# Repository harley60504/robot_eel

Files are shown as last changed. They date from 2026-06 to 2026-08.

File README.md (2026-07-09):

# Robot Eel

This repository contains the robot eel desktop release, ESP32 firmware, MuJoCo simulation and PPO/RL training tools, mobile Flutter app sources, real-video analysis scripts, and 3D-print assets.

## Folder Layout

- `Release/` - Packaged Windows desktop app plus the desktop Python backend.
- `robot_eel/` - ESP32 camera-board and control-board firmware.
- `mujoco_simulation/` - MuJoCo model, current RL train/view GUI, gait JSON files, plotting scripts, and PPO/RL training code.
- `flutter_esp_control_mobile/` - Flutter mobile app project and its own mobile-side Python backend.
- `real_movie_analysis/` - Real-video tracking and trajectory analysis scripts.
- `real_movie/` - Real experiment video/data files.
- `3D_print/` - STL assets for the eel body.

## Python Setup

Install the shared Python dependencies from the repository root:

```powershell
python -m pip install -r requirements.txt
```

The root `requirements.txt` is shared by the packaged desktop backend and the MuJoCo simulation tools. It currently pins the tested desktop/backend, MuJoCo, RL, plotting, OpenCV, and RealSense packages.

Tested MuJoCo/RL environment:

```text
Python 3.13.7
MuJoCo 3.4.0
Gymnasium 1.2.2
Stable-Baselines3 2.7.1
```

## Desktop App

Run the packaged Windows app from the repository root:

```powershell
cd Release
.\flutter_esp_control.exe
```

The app uses the Python backend in `Release/python_backend`. If the backend does not start automatically, start it manually from the repository root:

```powershell
python -m pip install -r requirements.txt
cd Release\python_backend
.\run_backend.bat
```

The backend serves the local API at:

```text
http://127.0.0.1:8765/
```

Backend details, camera modes, and GoPro/RealSense notes are in:

```text
Release/python_backend/README.md
```

## MuJoCo Simulation

Run these commands from the repository root. Install dependencies first if needed:

```powershell
python -m pip install -r requirements.txt
cd mujoco_simulation
```

Open the current training/export/plot/view GUI:

```powershell
python eel_pipeline_gui.py
```

View a saved fixed gait directly in MuJoCo:

```powershell
python view_gait.py gaits/straight.json
```

Plot fixed-gait trajectories:

```powershell
python plot_fixed_gait_trajectories.py
```

Train PPO policies:

```powershell
python train_free_swim_rl.py
python train_turning_rl.py --turn-direction left --target-yaw-rate 0.45 --output outputs/zips/ppo_turn_left_shape_bias
python train_turning_rl.py --turn-direction right --target-yaw-rate 0.45 --output outputs/zips/ppo_turn_right_shape_bias
```

Run the free-swim paper batch pipeline:

```powershell
python run_free_swim_paper_10.py
```

For detailed RL training, export, parameter, and GUI-testing commands, see:

```text
mujoco_simulation/RL_GAIT_TRAINING_GUIDE.md
```

Current default fixed gaits are in `mujoco_simulation/gaits/`. RL and batch outputs are written under `mujoco_simulation/outputs/`.

Older rectangle-course, tethered-swim, and legacy exporter/viewer scripts are kept under:

```text
mujoco_simulation/legacy_unused/
```

## Firmware

The ESP32 firmware files are under `robot_eel/`:

- `robot_eel/camera/` - ESP32 camera board, Wi-Fi, HTTP/WebSocket API, camera stream, CSV download, UART bridge, and app-facing control endpoints.
- `robot_eel/control/` - ESP32 control board, CPG gait generation, servo control, UART receive/transmit packets, and servo telemetry.
- `robot_eel/cpg_standalone/` - Standalone CPG-related firmware experiments.

The camera board is the app-facing board. It relays control commands to the control board over UART and receives servo telemetry back from the control board.

Shared packet/header files include:

```text
ControlParamsPacket.h
ServoTargetPacket.h
ServoCenterPacket.h
ServoStatusPacket.h
UartPacketChecksum.h
```

## Other Tools

- Mobile app work is in `flutter_esp_control_mobile/`; see that folder's README for mobile-specific setup.
- Real-video analysis scripts and notes are in `real_movie_analysis/`.
- 3D-print STL files are in `3D_print/eel_stl/`.

## Notes

- The current MuJoCo model entry point is `mujoco_simulation/eel.xml`.
- `eel.xml` includes `mujoco_simulation/environment_3x1_5.xml`; the file name is legacy, but the current XML defines a shared `20 m x 20 m` visual tank with `x/y = -10 ~ +10 m`.
- The default simulation start position is `x=0.0, y=0.0`.
- The repository includes recorded videos under `Release/python_backend/recordings/` and `robot_eel/recordings/`; these files may be large.

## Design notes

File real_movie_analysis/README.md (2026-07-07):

# Real Movie Analysis Scripts

This folder keeps only the analysis code for real robot videos. Raw videos, recordings, CSVs, generated figures, and dated analysis output folders are ignored by Git.

## Setup

Run commands from the repository root:

```powershell
cd C:\Users\ytyla\Documents\GitHub\robot_eel
```

Install the Python packages used by these scripts if needed:

```powershell
pip install opencv-python numpy matplotlib
```

The default input video folder is `real_movie/`. Generated analysis folders should stay under `real_movie_analysis/`; those outputs are ignored by Git.

## Typical Workflow

1. Track the red LED marker in the real videos:

```powershell
python real_movie_analysis\analyze_red_dot_videos.py --video-dir real_movie --out-dir real_movie_analysis\2026-07-08
```

2. Aggregate measured trial metrics across one or more analysis folders:

```powershell
python real_movie_analysis\aggregate_real_trials_per_lap.py real_movie_analysis\2026-07-08 --out-dir real_movie_analysis\2026-07-08_summary
```

3. Draw trajectory or posture figures from the generated analysis folder:

```powershell
python real_movie_analysis\draw_time_colored_fitted_trajectories.py real_movie_analysis\2026-07-08
python real_movie_analysis\draw_relative_pose_figures.py real_movie_analysis\2026-07-08
python real_movie_analysis\draw_relative_pose_adaptive.py real_movie_analysis\2026-07-08 --video-root real_movie
```

## Script Reference

### `analyze_red_dot_videos.py`

Tracks the red marker in each `.mp4`, fits straight or turning metrics, and writes per-video analysis outputs.

Common command:

```powershell
python real_movie_analysis\analyze_red_dot_videos.py --video-dir real_movie --out-dir real_movie_analysis\2026-07-08
```

Useful options:

- `--videos name1 name2`: process only specific video filenames or stems.
- `--sample-count 5`: number of representative frames to export.
- `--max-seconds 15`: analyze only the first N seconds.
- `--px-per-m 269.2105609870623`: pixel-to-meter calibration scale.
- `--straight-start-seconds 4 --straight-seconds 12`: measurement window for straight swimming.
- `--turn-start-seconds 2 --turn-trim-last-seconds 3`: measurement window for turning.

Main outputs:

- Per-video folder with `summary.json`, `red_dot_tracking.csv`, representative frames, trajectory plot, and fit overlay video.
- Top-level `summary.csv`, `summary.json`, and `command_error_summary.csv`.

### `aggregate_real_trials_per_lap.py`

Reads per-video `summary.json` files and averages unique trials by condition.

```powershell
python real_movie_analysis\aggregate_real_trials_per_lap.py real_movie_analysis\2026-07-08 --out-dir real_movie_analysis\2026-07-08_summary
```

You can pass multiple roots:

```powershell
python real_movie_analysis\aggregate_real_trials_per_lap.py real_movie_analysis\2026-07-02 real_movie_analysis\2026-07-03 --out-dir real_movie_analysis\combined_summary
```

Outputs:

- `trial_metrics.csv`
- `condition_summary.csv`
- `condition_summary.json`

### `draw_time_colored_fitted_trajectories.py`

Draws time-colored trajectories with fitted circles or straight-line fits.

```powershell
python real_movie_analysis\draw_time_colored_fitted_trajectories.py real_movie_analysis\2026-07-08
```

Optional:

```powershell
python real_movie_analysis\draw_time_colored_fitted_trajectories.py real_movie_analysis\2026-07-08 --out-dir real_movie_analysis\2026-07-08_time_plots
```

Outputs individual plots plus a selected 9-panel montage.

### `draw_relative_pose_figures.py`

Draws real LED posture figures using the representative clean frames generated by `analyze_red_dot_videos.py`.

```powershell
python real_movie_analysis\draw_relative_pose_figures.py real_movie_analysis\2026-07-08
```

Useful options:

- `--out-dir PATH`: custom output folder.
- `--sample-count 5`: how many representative frames to use.
- `--max-poses 5`: max eel poses drawn per video.
- `--prefix LABEL`: contact-sheet filename prefix.

### `draw_relative_pose_adaptive.py`

Draws adaptive posture figures directly against the original videos and analysis outputs. Use this when you want the more polished teal/red adaptive figure style.

```powershell
python real_movie_analysis\draw_relative_pose_adaptive.py real_movie_analysis\2026-07-08 --video-root real_movie
```

Useful options:

- `--out-dir PATH`: custom output folder.
- `--label LABEL`: contact-sheet filename prefix.
- `--title-prefix TEXT`: prefix before each video title.
- `--px-per-m VALUE`: calibration scale override.

## Notes

- The scripts infer command type from filenames, such as `targetv17`, `turn_left`, `r03`, or `y05`.
- Keep raw videos in `real_movie/` and backend recording logs in `Release/python_backend/recordings/`; both are ignored by Git.
- Keep generated analysis outputs under `real_movie_analysis/`; only the root-level `.py` files and this README are meant to be committed.

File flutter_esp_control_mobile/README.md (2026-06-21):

# flutter_esp_control

ESP32 robot eel control panel.

## Run

Default development target is Windows:

```powershell
flutter run -d windows
```

The web target is not used for this app.

For help getting started with Flutter development, view the
[online documentation](https://docs.flutter.dev/), which offers tutorials,
samples, guidance on mobile development, and a full API reference.

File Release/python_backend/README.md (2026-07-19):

# Robot Eel Python Backend

This folder is the Python sidecar used by the Flutter desktop app.

Flutter starts this backend automatically on desktop when the Python page
`Start` button is pressed and `http://127.0.0.1:8765/` is not already running.

ESP32 camera-board ports:

- HTTP `80`: Wi-Fi API, servo CSV download, and cache clear/status.
- WebSocket `81`: camera stream.
- WebSocket `82`: Flutter/manual control commands.
- WebSocket `83`: Python backend control commands.
- WebSocket `84`: servo-status telemetry.

The backend sends control JSON to port `83`. Flutter keeps using port `82` for
manual control, and servo status is received from port `84`, so telemetry does
not compete with control commands.

Camera-board firmware files are split by interface:

- `CameraStreamWs.*`: camera WebSocket stream.
- `ControlWsServer.*`: Flutter/Python control WebSockets.
- `ServoStatusWs.*`: servo telemetry WebSocket and CSV cache.
- `HttpApi.*`: HTTP routes for Wi-Fi and servo-log download.

UART packet headers are mirrored on both ESP32 boards:

- `ControlParamsPacket.h`: CPG/control-mode parameters, header `0xAA`.
- `ServoTargetPacket.h`: direct servo target angles, header `0xAB`.
- `ServoCenterPacket.h`: servo center calibration, optional NVS save, header `0xAC`.
- `ServoStatusPacket.h`: control-board telemetry back to the camera board, header `0xBB`.
- `UartPacketChecksum.h`: shared XOR checksum helper for UART packets.

## Install

```bat
cd ..\..
python -m pip install -r requirements.txt
```

## Run Manually

```bat
run_backend.bat
```

## GoPro Wi-Fi Camera

This release backend defaults to GoPro Wi-Fi preview mode.

- GoPro API: `http://10.5.5.9:8080`
- Preview stream: `udp://0.0.0.0:8554`
- Preview/recording output: `recordings\clean_v_YYYYMMDD_HHMMSS.mp4`

Before starting preview or recording, connect Windows to the GoPro Wi-Fi
network. Then run:

```bat
run_backend.bat
```

Check the GoPro connection:

```text
http://127.0.0.1:8765/gopro/state
```

When `/preview/start` or `/recording/start` is called, the backend first sends:

```text
/gopro/camera/stream/start?port=8554
```

and then records the UDP preview stream with OpenCV/FFmpeg.

The standalone preview helper also defaults to GoPro:

```bat
preview_camera.bat
```

## Camera Modes

The backend supports three camera modes for preview and recording:

- `rtsp`: original Wi-Fi RTSP camera.
- `opengopro_preview`: GoPro Wi-Fi OpenGoPro preview stream.
- `realsense_d435i_color_480p`: Intel RealSense D435i color stream only, `848 x 480`, better for lights-off recordings.
- `realsense_d435i_color_1080p`: Intel RealSense D435i color stream only, `1920 x 1080`, better for lights-on recordings.
- `realsense_d435i_depth`: Intel RealSense D435i aligned depth colormap only.
- `realsense_d435i_color_depth`: Intel RealSense D435i color + aligned depth stream.

Switch mode while preview and recording are stopped:

```text
POST http://127.0.0.1:8765/settings/camera_mode
{"camera_mode":"rtsp"}

POST http://127.0.0.1:8765/settings/camera_mode
{"camera_mode":"opengopro_preview"}

POST http://127.0.0.1:8765/settings/camera_mode
{"camera_mode":"realsense_d435i_color_480p"}

POST http://127.0.0.1:8765/settings/camera_mode
{"camera_mode":"realsense_d435i_color_1080p"}

POST http://127.0.0.1:8765/settings/camera_mode
{"camera_mode":"realsense_d435i_depth"}

POST http://127.0.0.1:8765/settings/camera_mode
{"camera_mode":"realsense_d435i_color_depth"}
```

For D435i, the Intel RealSense Python package is included in the repository root requirements:

```bat
cd ..\..
python -m pip install -r requirements.txt
```

Use `camera_mode_d435i_color_1080p.bat` for lights-on recordings and
`camera_mode_d435i_color_480p.bat` for lights-off recordings. The
`camera_mode_d435i_color.bat`, `camera_mode_d435i_depth.bat`, and
`camera_mode_d435i_color_depth.bat` files switch between common D435i outputs.
The combined mode records a side-by-side frame: color on the left, aligned
depth colormap on the right.

The D435i RGB and depth stream size is `848 x 480 @ 30 FPS`. Color-only and
depth-only output are `848 x 480`; combined color+depth output is
`1696 x 480`. RealSense frames are not stretched to `1920 x 1080`, so the
preview keeps the camera's real aspect ratio. The source name shown by the
backend is:

```text
realsense://d435i/color_depth
```

## Build Note

When distributing the Flutter desktop build, keep this `python_backend` folder
next to the built Flutter executable, or package it later as a standalone
`robot_eel_backend.exe`.

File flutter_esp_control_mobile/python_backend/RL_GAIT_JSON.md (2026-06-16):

# RL Gait JSON

This backend can load fixed gait JSON files exported from the MuJoCo PPO turning pipeline.

## JSON Folder

Put exported RL gait JSON files here:

```text
Release/python_backend/json/
```

On startup, `angle_generator.py` loads JSON files in this priority order:

1. `ROBOT_EEL_RL_GAIT_DIR` environment variable, if set
2. `Release/python_backend/json/`
3. `mujoco_simulation/outputs/json/rl_gaits/`

If two files have the same gait `name`, the first one found is used.

## Select A Gait

The backend exposes loaded gaits through:

```http
GET /gaits
```

To switch gait:

```http
POST /set_gait
Content-Type: application/json

{"gait": "ppo_turn_right_a20_y07_run01"}
```

`set_gait()` also accepts a direct JSON file path, for example:

```json
{"gait": "C:/Users/ytyla/Documents/GitHub/robot_eel/Release/python_backend/json/ppo_turn_right_a20_y07_run01.json"}
```

## Parameter Mapping

The JSON fields map to ESP32 CPG params like this:

| JSON field | Backend / ESP32 field | Unit |
| --- | --- | --- |
| `ajoint` | `Ajoint` | degrees |
| `freq` | `frequency` | Hz |
| `wavelength` | `lambda` | body-length scale |
| `amp_scales` | `ampScales` | unitless |
| `phase_lags` | `phaseLags` | radians |
| `joint_bias` | `jointBiasDeg` | JSON radians -> degrees |

The Hopf CPG constants are matched with the MuJoCo/ESP32 implementation:

```text
r init = 0.25
theta init = phase offsets
alpha = 4.0
k_couple = 0.35
mu = ampScales^2
output = Ajoint * r * cos(theta) + jointBiasDeg
```

## Practical Use

For real-fish CPG output, use backend `output_mode = "cpg"`. The backend sends `set_param` to ESP32, and ESP32 runs the CPG locally.

If the backend is already running, restart it after replacing files in `Release/python_backend/json/`, or call `set_gait()` with a direct JSON path to load one file immediately.

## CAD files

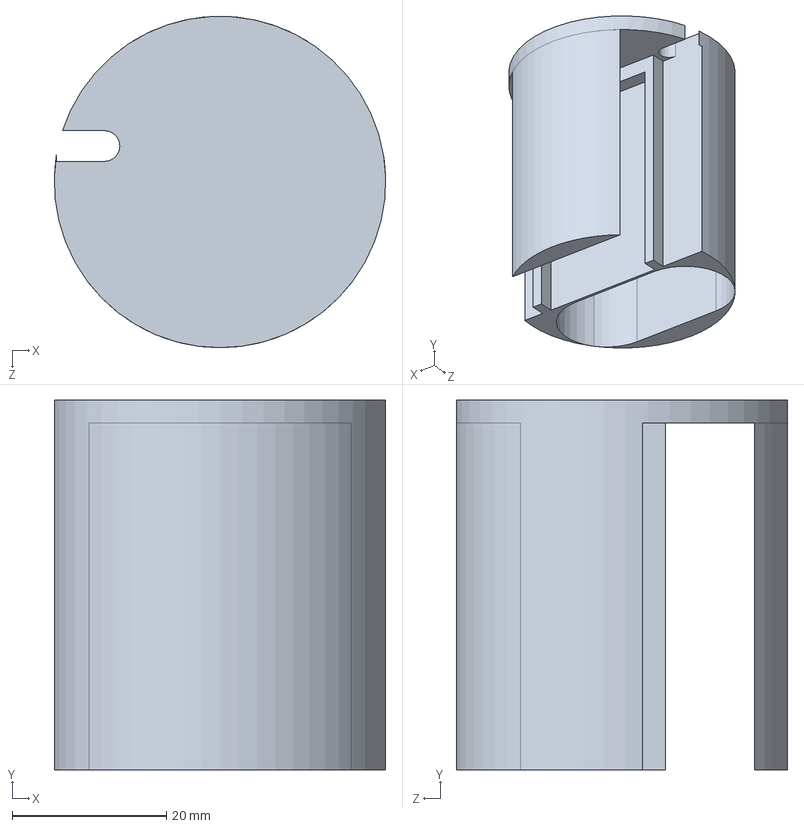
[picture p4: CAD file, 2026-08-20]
3D_print/eel_stl/battery_room.SLDPRT
43.0 x 48.0 x 43.0 mm

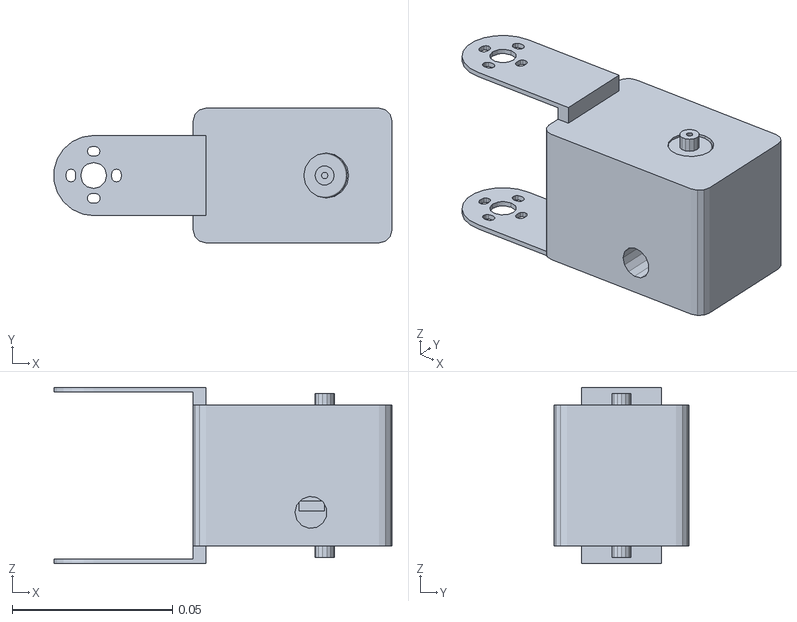
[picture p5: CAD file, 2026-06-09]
mujoco_simulation/eel_urdf/meshes/servo1.STL
0.105 x 0.042 x 0.055

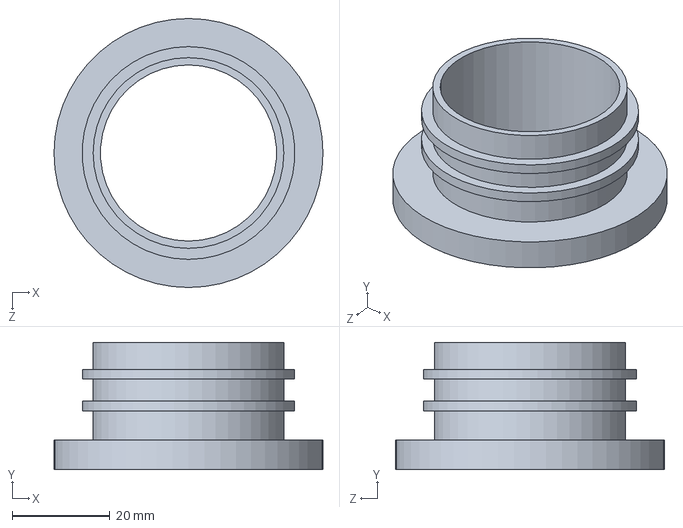
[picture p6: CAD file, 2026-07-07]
3D_print/eel_stl/lx_224_lib.SLDPRT
55.0 x 26.0 x 55.0 mm

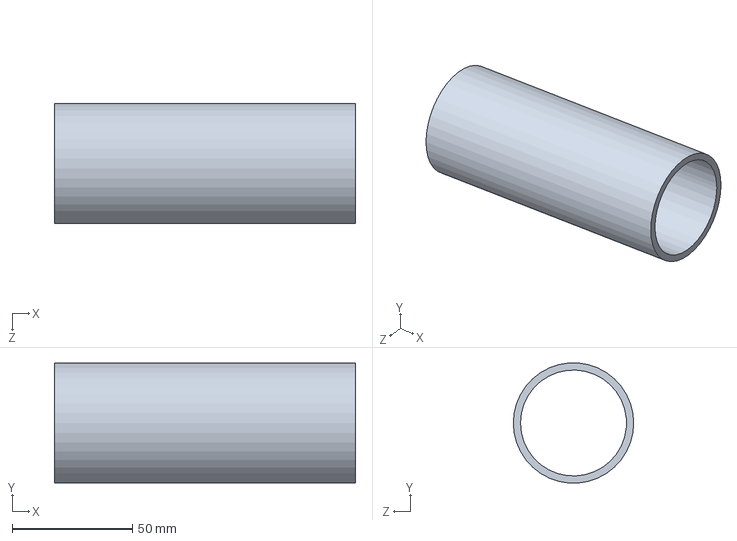
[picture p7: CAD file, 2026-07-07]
3D_print/eel_stl/head.SLDPRT
125.0 x 49.8 x 50.0 mm

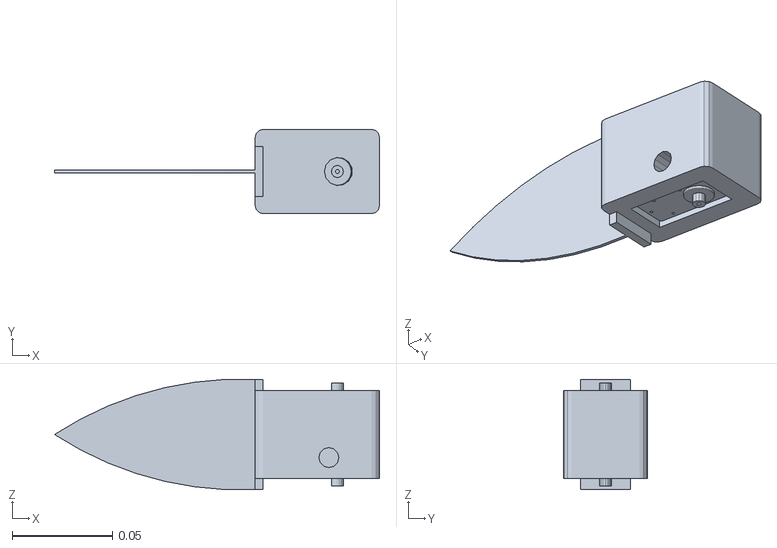
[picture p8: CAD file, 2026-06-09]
mujoco_simulation/eel_urdf/meshes/servo6.STL
0.162 x 0.042 x 0.055

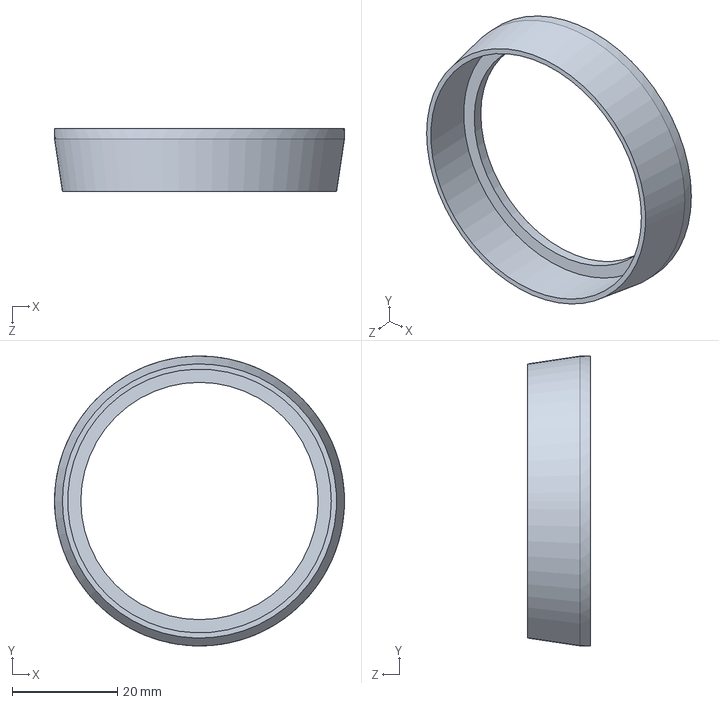
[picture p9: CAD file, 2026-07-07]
3D_print/eel_stl/lib.SLDPRT
55.0 x 55.0 x 12.0 mm

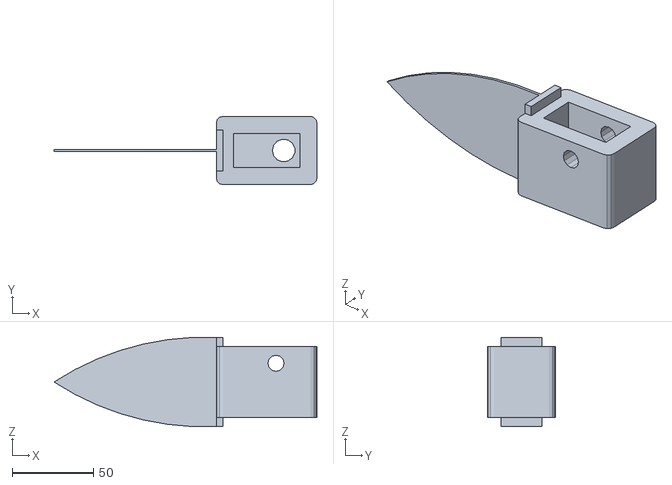
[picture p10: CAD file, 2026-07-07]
3D_print/eel_stl/lx_224_tail2.STL
162.0 x 42.0 x 55.0

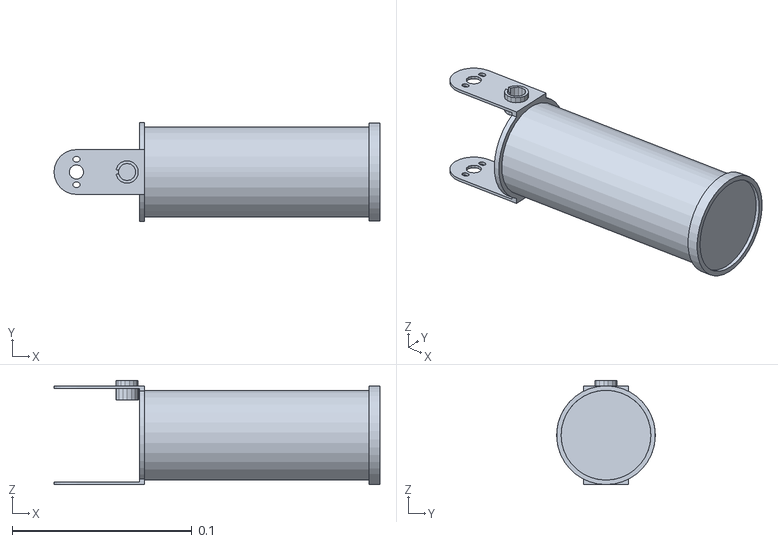
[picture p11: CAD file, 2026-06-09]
mujoco_simulation/eel_urdf/meshes/base_link.STL
0.182 x 0.055 x 0.058

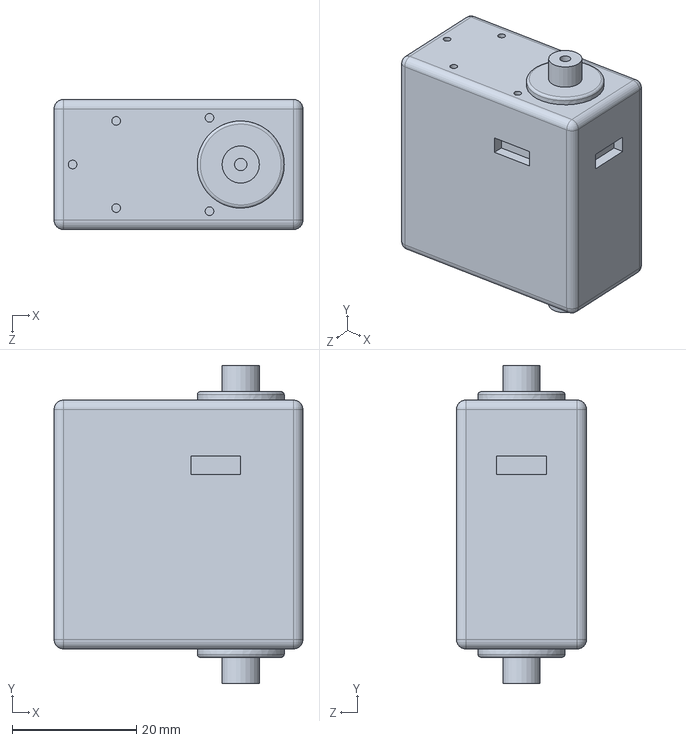
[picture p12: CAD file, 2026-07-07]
3D_print/eel_stl/LX-2242.SLDPRT
40.0 x 51.1 x 20.9 mm

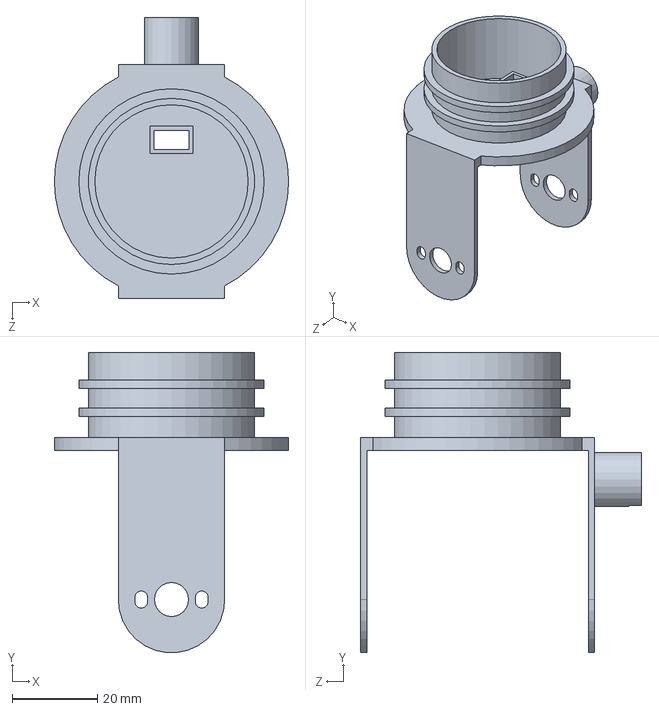
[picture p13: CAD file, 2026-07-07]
3D_print/eel_stl/lib_tail.SLDPRT
55.0 x 70.4 x 66.0 mm

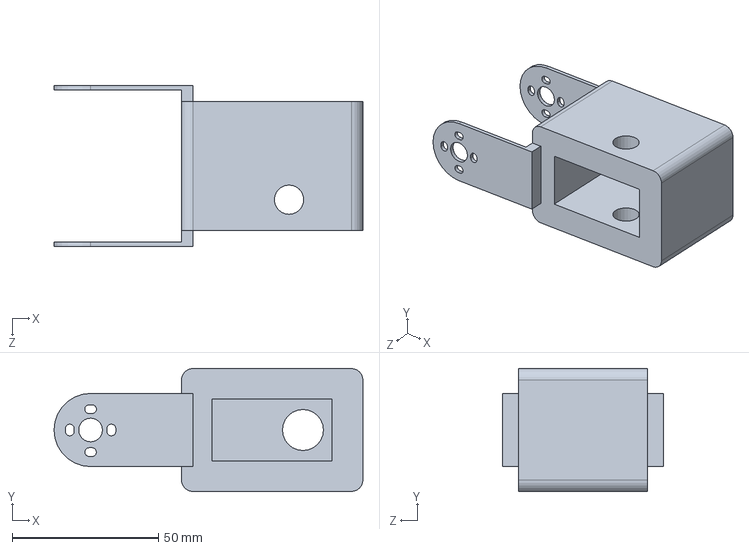
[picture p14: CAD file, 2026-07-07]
3D_print/eel_stl/lx_224_arm.SLDPRT
105.5 x 42.0 x 55.0 mm

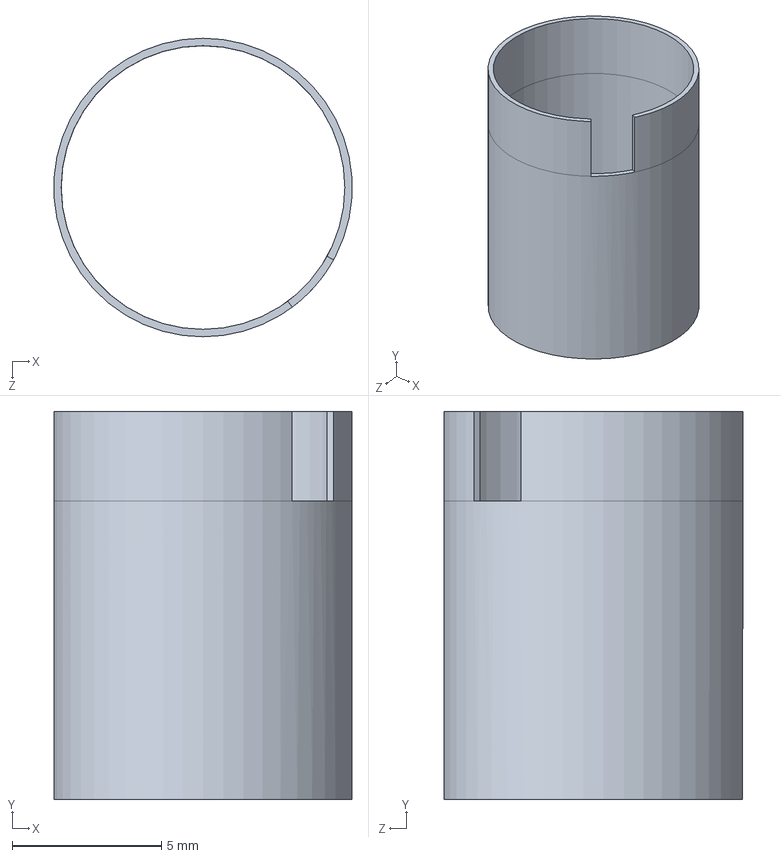
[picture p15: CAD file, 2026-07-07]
3D_print/eel_stl/wifi.SLDPRT
9.98 x 13.0 x 10.0 mm

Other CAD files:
mujoco_simulation/eel_urdf/meshes/servo3.STL
mujoco_simulation/eel_urdf/meshes/servo2.STL
mujoco_simulation/eel_urdf/meshes/servo4.STL
3D_print/eel_stl/lx_224_tailSLDPRT.SLDPRT
mujoco_simulation/eel_urdf/meshes/servo5.STL
3D_print/eel_stl/lx_224_arm2.STL
3D_print/eel_stl/battery_room.STL
3D_print/eel_stl/glass.SLDPRT
3D_print/eel_stl/lib.STL
3D_print/eel_stl/lib_tail.STL
3D_print/eel_stl/lx_224_arm.STL
3D_print/eel_stl/lx_224_lib.STL
3D_print/eel_stl/wifi.STL

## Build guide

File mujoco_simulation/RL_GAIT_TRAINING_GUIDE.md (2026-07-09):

# RL Gait Training Guide

This guide collects the commands for training PPO gaits, exporting trained policies to gait JSON files, and checking the result in the MuJoCo GUI.

Run all commands from the MuJoCo simulation folder:

```powershell
cd C:\Users\ytyla\Documents\GitHub\robot_eel\mujoco_simulation
```

Install required packages first if this is a new Python environment:

```powershell
cd ..
python -m pip install -r requirements.txt
cd mujoco_simulation
```

## 1. File outputs and what they mean

| Output | Meaning | Used by |
|---|---|---|
| `outputs/zips/ppo_free_swim_shape.zip` | PPO model for straight free-swim shape tuning | `export_rl_gait_json.py` |
| `outputs/zips/ppo_turn_left_shape_bias.zip` | PPO model for left turning gait training | `export_turning_rl_gait_json.py` |
| `outputs/zips/ppo_turn_right_shape_bias.zip` | PPO model for right turning gait training | `export_turning_rl_gait_json.py` |
| `outputs/json/rl_gaits/rl_straight.json` | fixed straight RL gait JSON | `eel_pipeline_gui.py`, `view_gait.py` |
| `outputs/json/rl_gaits/rl_turn_left.json` | fixed left-turn RL gait JSON | `eel_pipeline_gui.py`, `view_gait.py`, `measure_turning.py` |
| `outputs/json/rl_gaits/rl_turn_right.json` | fixed right-turn RL gait JSON | `eel_pipeline_gui.py`, `view_gait.py`, `measure_turning.py` |

`eel_pipeline_gui.py` is the current training, export, plotting, and viewing GUI. The older `gait_gui.py` was moved to `legacy_unused/`.

## 2. Straight free-swim PPO

Straight free-swim RL trains only CPG shape parameters:

```text
6 amp_scales + 5 phase_lags = 11 action values
```

It does not train `joint_bias`, so it is mainly for straight swimming.

### Train straight PPO

```powershell
python train_free_swim_rl.py --timesteps 500000 --output outputs/zips/ppo_free_swim_shape
```

### Continue straight PPO training

```powershell
python train_free_swim_rl.py --load-model outputs/zips/ppo_free_swim_shape.zip --timesteps 300000 --output outputs/zips/ppo_free_swim_shape
```

### Export straight PPO to gait JSON

```powershell
python export_rl_gait_json.py --model outputs/zips/ppo_free_swim_shape.zip --output outputs/json/rl_gaits/rl_straight.json
```

### Open GUI and test

```powershell
python eel_pipeline_gui.py
```

In the GUI, select `Fixed Gait`, press `Refresh`, then choose `[RL] rl_straight`.

## 3. Turning PPO

Turning RL trains CPG shape and static joint offset:

```text
6 amp_scales + 5 phase_lags + 6 joint_bias = 17 action values
```

This is the version used to train `rl_turn_left.json` and `rl_turn_right.json`.

The turning reward encourages:

```text
+ useful swimming speed
- yaw-rate error
- optional turn-radius error
- wrong turn direction
- lateral slip
- energy use
- action jumping
- joint_bias jumping
```

### Train left-turn PPO

```powershell
python train_turning_rl.py --turn-direction left --target-yaw-rate 0.45 --timesteps 500000 --output outputs/zips/ppo_turn_left_shape_bias
```

### Continue left-turn PPO training

```powershell
python train_turning_rl.py --turn-direction left --target-yaw-rate 0.45 --load-model outputs/zips/ppo_turn_left_shape_bias.zip --timesteps 300000 --output outputs/zips/ppo_turn_left_shape_bias
```

### Export left-turn PPO to gait JSON

```powershell
python export_turning_rl_gait_json.py --turn-direction left --target-yaw-rate 0.45 --model outputs/zips/ppo_turn_left_shape_bias.zip --output outputs/json/rl_gaits/rl_turn_left.json
```

### Measure left-turn gait

```powershell
python measure_turning.py --gait outputs/json/rl_gaits/rl_turn_left.json
```

### Train right-turn PPO

```powershell
python train_turning_rl.py --turn-direction right --target-yaw-rate 0.45 --timesteps 500000 --output outputs/zips/ppo_turn_right_shape_bias
```

### Continue right-turn PPO training

```powershell
python train_turning_rl.py --turn-direction right --target-yaw-rate 0.45 --load-model outputs/zips/ppo_turn_right_shape_bias.zip --timesteps 300000 --output outputs/zips/ppo_turn_right_shape_bias
```

### Export right-turn PPO to gait JSON

```powershell
python export_turning_rl_gait_json.py --turn-direction right --target-yaw-rate 0.45 --model outputs/zips/ppo_turn_right_shape_bias.zip --output outputs/json/rl_gaits/rl_turn_right.json
```

### Measure right-turn gait

```powershell
python measure_turning.py --gait outputs/json/rl_gaits/rl_turn_right.json
```

## 4. Common training parameters

These parameters can be used with `train_free_swim_rl.py` and `train_turning_rl.py` unless noted.

| Parameter | Meaning | Default / common value | What to change |
|---|---|---|---|
| `--timesteps` | Number of PPO training steps for this run | `100000` straight, `150000` turning default; recommended `300000~500000` | Increase if reward is still improving |
| `--output` | Output model path without `.zip` | `outputs/zips/ppo_*` | Change to keep multiple experiments |
| `--load-model` | Existing `.zip` model to continue training | none | Use this to resume training |
| `--episode-seconds` | Simulation seconds per episode | straight `8`, turning `10` | Longer episodes give more stable metrics but train slower |
| `--warmup-seconds` | Seconds with no reward at episode start | `2` | Increase if CPG startup is unstable; decrease if collecting reward too late |
| `--freq` | CPG frequency in Hz | `1.0` | Higher can swim faster but may become unstable |
| `--wavelength` | CPG wavelength parameter | `1.6275` | Change if body wave looks too compressed or too stretched |
| `--ajoint` | Base joint amplitude in degrees | `15` | Larger gives stronger motion but can hit limits or waste energy |
| `--amp-scale-lows` | Lower bound for 6 amplitude scale actions | script default | Narrow if RL explores too aggressively |
| `--amp-scale-highs` | Upper bound for 6 amplitude scale actions | script default | Increase if motion is too weak; decrease if unstable |
| `--phase-lag-lows` | Lower bound for 5 adjacent-joint phase lags | script default | Narrow if phase becomes unrealistic |
| `--phase-lag-highs` | Upper bound for 5 adjacent-joint phase lags | script default | Increase only if the wave needs more delay |

Example of changing amplitude and frequency:

```powershell
python train_free_swim_rl.py --freq 1.2 --ajoint 18 --timesteps 300000 --output outputs/zips/ppo_free_swim_f12_a18
```

Example of narrower action bounds:

```powershell
python train_free_swim_rl.py --amp-scale-lows 1.10,0.95,0.90,0.95,1.00,1.05 --amp-scale-highs 1.30,1.15,1.10,1.15,1.25,1.35 --timesteps 300000 --output outputs/zips/ppo_free_swim_narrow
```

## 5. Turning-only parameters

These parameters are for `train_turning_rl.py` and `export_turning_rl_gait_json.py`.

| Parameter | Meaning | Default / common value | What to change |
|---|---|---|---|
| `--turn-direction` | Which direction to train or export | `left` or `right` | Use `left` for left turn, `right` for right turn |
| `--target-yaw-rate` | Target absolute yaw rate in rad/s | `0.45` | Increase for tighter/faster turning; decrease for wider turning |
| `--target-radius` | Optional target turn radius in meters | none | Use if you care more about radius than yaw rate |
| `--joint-bias-low` | Minimum learned joint bias in radians | `-0.30` | More negative allows stronger right-side bias but may destabilize |
| `--joint-bias-high` | Maximum learned joint bias in radians | `0.30` | More positive allows stronger left-side bias but may destabilize |
| `--speed-weight` | Reward weight for speed | `0.60` | Increase if it turns but barely moves forward |
| `--yaw-rate-weight` | Reward weight for matching yaw rate | `1.20` | Increase if turn rate is far from target |
| `--radius-weight` | Reward weight for matching radius | `0.00`, or `0.40` when `--target-radius` is used | Increase when training a fixed radius |
| `--turn-direction-weight` | Penalty for turning the wrong direction | `0.30` | Increase if it sometimes turns the wrong way |
| `--lateral-speed-weight` | Penalty for side slip | `0.05` | Increase if it slides sideways too much |
| `--energy-weight` | Penalty for large control output | `0.02` | Increase if the gait is too aggressive |
| `--smoothness-weight` | Penalty for action jumps | `0.02` | Increase if action changes are unstable |
| `--bias-smoothness-weight` | Penalty for joint_bias jumps | `0.02` | Increase if learned bias is noisy |

### Target yaw rate examples

Wider and gentler turn:

```powershell
python train_turning_rl.py --turn-direction left --target-yaw-rate 0.30 --timesteps 500000 --output outputs/zips/ppo_turn_left_yaw030
```

Tighter and stronger turn:

```powershell
python train_turning_rl.py --turn-direction left --target-yaw-rate 0.65 --timesteps 500000 --output outputs/zips/ppo_turn_left_yaw065
```

If `--target-yaw-rate` is too high, the policy may learn unstable bias, hit boundaries, or lose forward motion.

### Target radius examples

Train left turn for about 0.8 m radius:

```powershell
python train_turning_rl.py --turn-direction left --target-yaw-rate 0.45 --target-radius 0.8 --timesteps 500000 --output outputs/zips/ppo_turn_left_r08
```

Export it:

```powershell
python export_turning_rl_gait_json.py --turn-direction left --target-yaw-rate 0.45 --target-radius 0.8 --model outputs/zips/ppo_turn_left_r08.zip --output outputs/json/rl_gaits/rl_turn_left_r08.json
```

## 6. Export parameters

These parameters are for `export_rl_gait_json.py` and `export_turning_rl_gait_json.py`.

| Parameter | Meaning | Default / common value | What to change |
|---|---|---|---|
| `--model` | Trained PPO `.zip` file | `outputs/zips/ppo_*.zip` | Must match the model you trained |
| `--output` | Output gait JSON path | `outputs/json/rl_gaits/*.json` | Change name to keep multiple versions |
| `--name` | Name stored inside the JSON | derived from file/direction | Change for GUI display |
| `--samples` | Number of steady-state actions collected before export | `300` | Increase for smoother average |
| `--max-episodes` | Maximum rollout episodes during export | `20` | Increase if export cannot collect enough samples |
| `--strategy` | How to collapse actions into one fixed gait | `mean` | Use `best-step` if mean is too weak; use `last` for final policy action |
| `--stochastic` | Use stochastic policy output during export | off | Usually keep off; deterministic is more repeatable |
| `--round` | Decimal places in JSON | `6` | Keep default unless file readability matters |

Recommended export strategy:

```powershell
python export_turning_rl_gait_json.py --turn-direction left --model outputs/zips/ppo_turn_left_shape_bias.zip --output outputs/json/rl_gaits/rl_turn_left.json --strategy mean --samples 300
```

If the averaged gait becomes too weak, try:

```powershell
python export_turning_rl_gait_json.py --turn-direction left --model outputs/zips/ppo_turn_left_shape_bias.zip --output outputs/json/rl_gaits/rl_turn_left_best.json --strategy best-step
```

## 7. How to judge whether training is healthy

During training, focus on these log fields:

| Log field | Good sign | Warning sign |
|---|---|---|
| `rollout/ep_rew_mean` | Slowly increases, or becomes less negative | Flat for a long time or suddenly drops |
| `rollout/ep_len_mean` | Near full episode length | Much shorter than expected, often means out-of-bounds termination |
| `train/approx_kl` | Around `0.001~0.03` | Larger than `0.1` often means unstable updates |
| `train/clip_fraction` | Usually below `0.2` | Very high for a long time can mean updates are too aggressive |
| `train/value_loss` | Can fluctuate, but not exploding | Keeps increasing without bound |
| `train/explained_variance` | Higher is better, often `0.5~1.0` | Near zero or negative for a long time |

Do not judge PPO only from `train/loss`. PPO loss can move up and down and still be normal.

## 8. Recommended workflow

For straight gait:

```powershell
python train_free_swim_rl.py --timesteps 500000 --output outputs/zips/ppo_free_swim_shape
python export_rl_gait_json.py --model outputs/zips/ppo_free_swim_shape.zip --output outputs/json/rl_gaits/rl_straight.json
python eel_pipeline_gui.py
```

For left and right turning gaits:

```powershell
python train_turning_rl.py --turn-direction left --target-yaw-rate 0.45 --timesteps 500000 --output outputs/zips/ppo_turn_left_shape_bias
python train_turning_rl.py --turn-direction right --target-yaw-rate 0.45 --timesteps 500000 --output outputs/zips/ppo_turn_right_shape_bias

python export_turning_rl_gait_json.py --turn-direction left --model outputs/zips/ppo_turn_left_shape_bias.zip --output outputs/json/rl_gaits/rl_turn_left.json
python export_turning_rl_gait_json.py --turn-direction right --model outputs/zips/ppo_turn_right_shape_bias.zip --output outputs/json/rl_gaits/rl_turn_right.json

python measure_turning.py --gait outputs/json/rl_gaits/rl_turn_left.json
python measure_turning.py --gait outputs/json/rl_gaits/rl_turn_right.json
python eel_pipeline_gui.py
```

## 9. What not to change first

Avoid changing these until the basic workflow works:

- XML model path.
- MuJoCo timestep.
- CPG implementation.
- Reward weights all at once.
- Very large `joint_bias` bounds such as `-0.8~0.8`.

Change one group of parameters at a time, then export and measure the resulting JSON.

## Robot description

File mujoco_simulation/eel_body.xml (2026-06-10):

<mujoco>
    <body name="base_link" pos="0.65 -0.35 -0.02">
      <joint name="root_x" type="slide" pos="0 0 0" axis="1 0 0" limited="false" armature="0.01" damping="0.1" />
      <joint name="root_y" type="slide" pos="0 0 0" axis="0 1 0" limited="false" armature="0.01" damping="0.1" />
      <joint name="root_z_rot" type="hinge" pos="0 0 0" axis="0 0 1" limited="false" armature="0.01" damping="0.001" />
      <inertial pos="0.062748 2.5587E-16 0.00026796" mass="0.275" fullinertia="1.425065E-04 3.227938E-04 3.149408E-04 -4.571260E-21 1.783569E-07 -9.915051E-23" />
      <geom name="base_link_collision" type="mesh" mesh="base_link_mesh" class="eel_collision_fluid" />
      <geom name="base_link_visual" type="mesh" mesh="base_link_mesh" contype="0" conaffinity="0" group="1" material="eel_mat" />
      <body name="servo1" pos="-0.035 0 0.025706">
        <geom name="servo1_joint_marker" type="sphere" size="0.008" pos="0 0 0" material="joint_marker_red" contype="0" conaffinity="0" group="2" />
        <inertial pos="-0.01159 -6.9584E-08 -0.025118" mass="0.11323" fullinertia="3.6169E-05 6.3328E-05 5.9619E-05 -4.7019E-10 -1.6398E-07 -4.8085E-12" />
        <joint name="servo1" pos="0 0 0" axis="0 0 -1" range="-1.5 1.5" actuatorfrcrange="-10 10" armature="0.05" damping="1.5" />
        <geom name="servo1_collision" type="mesh" mesh="servo1_mesh" class="eel_collision_fluid" />
        <geom name="servo1_visual" type="mesh" mesh="servo1_mesh" contype="0" conaffinity="0" group="1" material="eel_mat" />
        <body name="servo2" pos="-0.072 0 0">
          <geom name="servo2_joint_marker" type="sphere" size="0.008" pos="0 0 0" material="joint_marker_red" contype="0" conaffinity="0" group="2" />
          <inertial pos="-0.01159 -6.9584E-08 -0.025118" mass="0.11323" fullinertia="3.6169E-05 6.3328E-05 5.9619E-05 -4.7019E-10 -1.6398E-07 -4.8085E-12" />
          <joint name="servo2" pos="0 0 0" axis="0 0 -1" range="-1.5 1.5" actuatorfrcrange="-10 10" armature="0.05" damping="1.5" />
          <geom name="servo2_collision" type="mesh" mesh="servo2_mesh" class="eel_collision_fluid" />
          <geom name="servo2_visual" type="mesh" mesh="servo2_mesh" contype="0" conaffinity="0" group="1" material="eel_mat" />
          <body name="servo3" pos="-0.072 0 0">
            <geom name="servo3_joint_marker" type="sphere" size="0.008" pos="0 0 0" material="joint_marker_red" contype="0" conaffinity="0" group="2" />
            <inertial pos="-0.01159 -6.9584E-08 -0.025118" mass="0.11323" fullinertia="3.6169E-05 6.3328E-05 5.9619E-05 -4.7019E-10 -1.6398E-07 -4.8085E-12" />
            <joint name="servo3" pos="0 0 0" axis="0 0 -1" range="-1.5 1.5" actuatorfrcrange="-10 10" armature="0.05" damping="1.5" />
            <geom name="servo3_collision" type="mesh" mesh="servo3_mesh" class="eel_collision_fluid" />
            <geom name="servo3_visual" type="mesh" mesh="servo3_mesh" contype="0" conaffinity="0" group="1" material="eel_mat" />
            <body name="servo4" pos="-0.072 0 0">
              <geom name="servo4_joint_marker" type="sphere" size="0.008" pos="0 0 0" material="joint_marker_red" contype="0" conaffinity="0" group="2" />
              <inertial pos="-0.01159 -6.9584E-08 -0.025118" mass="0.11323" fullinertia="3.6169E-05 6.3328E-05 5.9619E-05 -4.7019E-10 -1.6398E-07 -4.8085E-12" />
              <joint name="servo4" pos="0 0 0" axis="0 0 -1" range="-1.5 1.5" actuatorfrcrange="-10 10" armature="0.05" damping="1.5" />
              <geom name="servo4_collision" type="mesh" mesh="servo4_mesh" class="eel_collision_fluid" />
              <geom name="servo4_visual" type="mesh" mesh="servo4_mesh" contype="0" conaffinity="0" group="1" material="eel_mat" />
              <body name="servo5" pos="-0.072 0 0">
                <geom name="servo5_joint_marker" type="sphere" size="0.008" pos="0 0 0" material="joint_marker_red" contype="0" conaffinity="0" group="2" />
                <inertial pos="-0.01159 -6.9584E-08 -0.025118" mass="0.11323" fullinertia="3.6169E-05 6.3328E-05 5.9619E-05 -4.7019E-10 -1.6398E-07 -4.8085E-12" />
                <joint name="servo5" pos="0 0 0" axis="0 0 -1" range="-1.5 1.5" actuatorfrcrange="-10 10" armature="0.05" damping="1.5" />
                <geom name="servo5_collision" type="mesh" mesh="servo5_mesh" class="eel_collision_fluid" />
                <geom name="servo5_visual" type="mesh" mesh="servo5_mesh" contype="0" conaffinity="0" group="1" material="eel_mat" />
                <body name="servo6" pos="-0.072 0 0">
                  <geom name="servo6_joint_marker" type="sphere" size="0.008" pos="0 0 0" material="joint_marker_red" contype="0" conaffinity="0" group="2" />
                  <inertial pos="-0.013811 2.5153E-17 -0.025129" mass="0.11626" fullinertia="3.5103E-05 8.4443E-05 8.1511E-05 2.7809E-20 -3.1447E-07 1.5836E-20" />
                  <joint name="servo6" pos="0 0 0" axis="0 0 -1" range="-1.5 1.5" actuatorfrcrange="-10 10" armature="0.05" damping="1.5" />
                  <geom name="servo6_collision" type="mesh" mesh="servo6_mesh" class="eel_collision_fluid" />
                  <geom name="servo6_visual" type="mesh" mesh="servo6_mesh" contype="0" conaffinity="0" group="1" material="eel_mat" />
                </body>
              </body>
            </body>
          </body>
        </body>
      </body>
    </body>
</mujoco>

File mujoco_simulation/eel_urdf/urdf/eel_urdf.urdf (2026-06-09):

<?xml version="1.0" encoding="utf-8"?>
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
<robot name="eel_urdf">
  <link name="base_link">
    <inertial>
      <origin xyz="0.062748 2.5587E-16 0.00026796" rpy="0 0 0" />
      <mass value="0.083903" />
      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
    </inertial>
    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
  </link>
  <link name="servo1">
    <inertial>
      <origin xyz="-0.01159 -6.9584E-08 -0.025118" rpy="0 0 0" />
      <mass value="0.11323" />
      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
    </inertial>
    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
  </link>
  <joint name="servo1" type="continuous">
    <origin xyz="-0.035 0 0.025706" rpy="0 0 0" />
    <parent link="base_link" />
    <child link="servo1" />
    <axis xyz="0 0 1" />
    <limit lower="0" upper="0" effort="0" velocity="0" />
  </joint>
  <link name="servo2">
    <inertial>
      <origin xyz="-0.01159 -6.9584E-08 -0.025118" rpy="0 0 0" />
      <mass value="0.11323" />
      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
    </inertial>
    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
  </link>
  <joint name="servo2" type="continuous">
    <origin xyz="-0.072 0 0" rpy="0 0 0" />
    <parent link="servo1" />
    <child link="servo2" />
    <axis xyz="0 0 1" />
    <limit lower="0" upper="0" effort="0" velocity="0" />
  </joint>
  <link name="servo3">
    <inertial>
      <origin xyz="-0.01159 -6.9584E-08 -0.025118" rpy="0 0 0" />
      <mass value="0.11323" />
      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
    </inertial>
    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
  </link>
  <joint name="servo3" type="continuous">
    <origin xyz="-0.072 0 0" rpy="0 0 0" />
    <parent link="servo2" />
    <child link="servo3" />
    <axis xyz="0 0 1" />
    <limit lower="0" upper="0" effort="0" velocity="0" />
  </joint>
  <link name="servo4">
    <inertial>
      <origin xyz="-0.01159 -6.9584E-08 -0.025118" rpy="0 0 0" />
      <mass value="0.11323" />
      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
    </inertial>
    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
  </link>
  <joint name="servo4" type="continuous">
    <origin xyz="-0.072 0 0" rpy="0 0 0" />
    <parent link="servo3" />
    <child link="servo4" />
    <axis xyz="0 0 1" />
    <limit lower="0" upper="0" effort="0" velocity="0" />
  </joint>
  <link name="servo5">
    <inertial>
      <origin xyz="-0.01159 -6.9584E-08 -0.025118" rpy="0 0 0" />
      <mass value="0.11323" />
      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
    </inertial>
    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
  </link>
  <joint name="servo5" type="continuous">
    <origin xyz="-0.072 0 0" rpy="0 0 0" />
    <parent link="servo4" />
    <child link="servo5" />
    <axis xyz="0 0 1" />
    <limit lower="0" upper="0" effort="0" velocity="0" />
  </joint>
  <link name="servo6">
    <inertial>
      <origin xyz="-0.013811 2.5153E-17 -0.025129" rpy="0 0 0" />
      <mass value="0.11626" />
      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
    </inertial>
    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
  </link>
  <joint name="servo6" type="continuous">
    <origin xyz="-0.072 0 0" rpy="0 0 0" />
    <parent link="servo5" />
    <child link="servo6" />
    <axis xyz="0 0 1" />
    <limit lower="0" upper="0" effort="0" velocity="0" />
  </joint>
</robot>

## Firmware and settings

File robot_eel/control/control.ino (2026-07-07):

#include <Arduino.h>
#include <Preferences.h>
#include "driver/uart.h"
#include "freertos/semphr.h"

#include "config.h"
#include "utils.h"
#include "cpg.h"
#include "servo.h"
#include "ServoStatusPacket.h"
#include "ControlParamsPacket.h"
#include "ServoTargetPacket.h"
#include "ServoCenterPacket.h"




// ServoStatusPacket
ServoStatusPacket g_status;
SemaphoreHandle_t statusMutex = NULL;
volatile uint32_t g_servoStatusSeq = 0;
// ==========================
//  Servo defaults
// ==========================
float servoDefaultAngles[bodyNum] = {120,120,120,120,120,120};
float angleDeg[bodyNum];
static Preferences servoCenterPrefs;

// ==========================
//  Control Parameters
// ==========================
// RL exported params: mujoco_simulation/gaits/rl_straight.json
float Ajoint       = 20.0f;  // deg
float frequency    = 1.0f;
float lambda       = 1.6275f;
float L            = 1.0f;
float ampScales[bodyNum] = {
  1.1f,
  0.95f,
  0.9f,
  1.071703f,
  1.161346f,
  1.273484f
};
float phaseLags[bodyNum - 1] = {
  0.614385f,
  0.622822f,
  0.615807f,
  0.615359f,
  0.608868f
};
float jointBiasDeg[bodyNum] = {0, 0, 0, 0, 0, 0};

bool  isPaused     = false;
int   controlMode  = 2;

// ==========================
HopfOscillator cpg[bodyNum];
unsigned long g_lastLogTime = 0;

// ==========================
// RX state (ControlParamsPacket)
// ==========================
static ControlParamsRxState camCtrlRx;

// ==========================
// RX state (ServoTargetPacket)
// ==========================
static ServoTargetRxState camTargetRx;
static ServoCenterRxState camCenterRx;

// ==========================
// UART servo-target cache (shared with servoTask)
// ==========================
volatile bool g_haveAngleCmd = false;
float g_uartTargetDeg[bodyNum] = {0};
volatile uint32_t g_lastAngleSeq = 0;

SemaphoreHandle_t angleMutex = NULL;

void loadServoCenters()
{
  servoCenterPrefs.begin("servo_center", true);
  for (int i = 0; i < bodyNum; i++)
  {
    char key[4];
    snprintf(key, sizeof(key), "s%d", i);
    servoDefaultAngles[i] = servoCenterPrefs.getFloat(key, servoDefaultAngles[i]);
  }
  servoCenterPrefs.end();

  Serial.print("[CENTER] loaded:");
  for (int i = 0; i < bodyNum; i++)
  {
    Serial.printf(" %.2f", servoDefaultAngles[i]);
  }
  Serial.println();
}

void saveServoCenters()
{
  servoCenterPrefs.begin("servo_center", false);
  for (int i = 0; i < bodyNum; i++)
  {
    char key[4];
    snprintf(key, sizeof(key), "s%d", i);
    servoCenterPrefs.putFloat(key, servoDefaultAngles[i]);
  }
  servoCenterPrefs.end();
  Serial.println("[CENTER] saved to NVS");
}

void applyServoCenters(const ServoCenterPacket &pkt)
{
  if (pkt.count != bodyNum) return;

  for (int i = 0; i < bodyNum; i++)
  {
    servoDefaultAngles[i] = constrain(pkt.centerDeg[i], 0.0f, 240.0f);
  }

  if (pkt.save)
  {
    saveServoCenters();
  }

  Serial.printf("[CENTER] packet OK seq=%lu save=%u\n",
                (unsigned long)pkt.seq, (unsigned)pkt.save);
}

// ==========================
// UART TX Task  (→ Camera): send control params
// ==========================
void cameraTxTask(void* pv)
{
  TickType_t lastWake = xTaskGetTickCount();

  while(true)
  {
    sendControlParamsUART(
      Serial2,
      Ajoint,
      frequency,
      lambda,
      L,
      ampScales,
      phaseLags,
      jointBiasDeg,
      isPaused,
      (uint8_t)controlMode,
      servoDefaultAngles
    );

    vTaskDelayUntil(&lastWake, pdMS_TO_TICKS(100));   // 10Hz
  }
}

// ==========================
// UART RX Task (← Camera): demux by header 0xAA / 0xAB
// ==========================
void cameraRxTask(void* pv)
{
  Serial.println("Camera RX Task started");

  while(true)
  {
    while(Serial2.available())
    {
      uint8_t b = Serial2.read();

      // =====================================================
      // 優先處理：如果 ServoTarget parser 正在接收，就只餵 Angle
      // =====================================================
      if (camTargetRx.receiving)
      {
        if (feedServoTargetRx(camTargetRx, b))
        {
          ServoTargetPacket &pkt = camTargetRx.pkt;

          if (pkt.count == bodyNum)
          {
            if (pkt.seq != g_lastAngleSeq)
            {
              if (angleMutex &&
                  xSemaphoreTake(angleMutex, portMAX_DELAY) == pdTRUE)
              {
                for (int i = 0; i < bodyNum; i++)
                {
                  g_uartTargetDeg[i] = pkt.targetDeg[i];
                }

                g_lastAngleSeq = pkt.seq;
                g_haveAngleCmd = true;

                xSemaphoreGive(angleMutex);
              }
            }
          }

          // Debug（可關）
          Serial.printf("[UART] ServoTargetPacket OK seq=%lu count=%u\n",
                        (unsigned long)pkt.seq, (unsigned)pkt.count);
        }

        // ✅ 已在 ServoTarget 狀態下，這個 byte 不要再給其他 parser
        continue;
      }

      // =====================================================
      // 優先處理：如果 Control parser 正在接收，就只餵 Control
      // =====================================================
      if (camCenterRx.receiving)
      {
        if (feedServoCenterRx(camCenterRx, b))
        {
          applyServoCenters(camCenterRx.pkt);
        }

        continue;
      }

      if (camCtrlRx.receiving)
      {
        if (feedControlParamsRx(camCtrlRx, b))
        {
          ControlParamsPacket &pkt = camCtrlRx.pkt;
          int previousMode = controlMode;

          Ajoint       = pkt.Ajoint;
          frequency    = pkt.frequency;
          lambda       = pkt.lambda;
          L            = pkt.L;
          for (int i = 0; i < bodyNum; i++) {
            ampScales[i] = pkt.ampScales[i];
            jointBiasDeg[i] = pkt.jointBiasDeg[i];
          }
          for (int i = 0; i < bodyNum - 1; i++) {
            phaseLags[i] = pkt.phaseLags[i];
          }
          isPaused     = pkt.isPaused;
          controlMode  = pkt.controlMode;

          // ✅ 如果切到非 ServoTarget 模式，把角度命令標記清掉（避免殘留）
          if (controlMode != MODE_UART_ANGLE) {
            g_haveAngleCmd = false;
          }

          if (previousMode != MODE_CPG && controlMode == MODE_CPG) {
            initCPG();
          }

          Serial.println("==== UART ← Camera (ControlParamsPacket) ====");
          Serial.printf("mode=%d pause=%d A=%.2f f=%.2f lambda=%.2f L=%.2f\n",
                        controlMode, (int)isPaused,
                        Ajoint, frequency, lambda, L);
        }

        // ✅ 已在 Control 狀態下，這個 byte 不要再給其他 parser
        continue;
      }

      // =====================================================
      // Idle 狀態：只認 header，才開始接收
      // =====================================================
      if (b == CONTROL_PARAMS_PACKET_HEADER)
      {
        // 啟動 Control parser（把 header 也放進去）
        feedControlParamsRx(camCtrlRx, b);
        continue;
      }

      if (b == SERVO_TARGET_PACKET_HEADER)
      {
        // 啟動 ServoTarget parser（把 header 也放進去）
        feedServoTargetRx(camTargetRx, b);
        continue;
      }

      if (b == SERVO_CENTER_PACKET_HEADER)
      {
        feedServoCenterRx(camCenterRx, b);
        continue;
      }

      // 其他 byte：丟棄
    }

    vTaskDelay(pdMS_TO_TICKS(1));
  }
}

// ==========================
// SETUP
// ==========================
void setup()
{
  Serial.begin(115200);
  delay(300);
  statusMutex = xSemaphoreCreateMutex();
  // ✅ 建立 angleMutex（很重要）
  angleMutex = xSemaphoreCreateMutex();

  if (!statusMutex || !angleMutex) {
    Serial.println("ERROR: Mutex create failed!");
    while (1) delay(1000);
  }
  // Servo UART (RS485)
  Serial1.begin(115200, SERIAL_8N1, SERVO_RX_PIN, SERVO_TX_PIN);
  uart_set_mode(UART_NUM_1, UART_MODE_RS485_HALF_DUPLEX);

  // Camera UART
  Serial2.begin(115200, SERIAL_8N1, CAMERA_RX_PIN, CAMERA_TX_PIN);

  Serial.println("Control Board Ready");
  loadServoCenters();

  initCPG();
  // Servo Task
  xTaskCreatePinnedToCore(
    servoTask,
    "servoTask",
    4096,
    nullptr,
    2,
    nullptr,
    1
  );

  // UART TX Task
  xTaskCreatePinnedToCore(
    cameraTxTask,
    "cameraTxTask",
    4096,
    nullptr,
    1,
    nullptr,
    0
  );

  // UART RX Task (demux Control + Angle)
  xTaskCreatePinnedToCore(
    cameraRxTask,
    "cameraRxTask",
    4096,
    nullptr,
    2,       // 建議比 TX 高一點點，避免 RX 積壓
    nullptr,
    0
  );

  // Servo status TX Task (回傳 target/actual/error)
  xTaskCreatePinnedToCore(
    servoStatusTxTask,
    "servoStatusTxTask",
    4096,
    nullptr,
    1,
    nullptr,
    0
  );
}

// ==========================
// MAIN LOOP
// ==========================
void loop()
{
}

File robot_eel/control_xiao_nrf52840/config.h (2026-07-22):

#pragma once
#include <Arduino.h>
#ifndef M_PI
#define M_PI 3.14159265358979323846
#endif
// =====================================================
// LX-224 Servo
// =====================================================
#define SERVO_TX_PIN D6
#define SERVO_RX_PIN D7
#define HEADER 0x55
#define CMD_MOVE_TIME_WRITE 0x01
#define CMD_READ_POS        0x1C
#define CMD_ID_WRITE        0x13
#define BROADCAST_ID 0xFE
#define bodyNum 6
// =====================================================
// Control modes (keep in sync with Flutter mode buttons)
// =====================================================
#define MODE_SIN         0
#define MODE_CPG         1
#define MODE_OFFSET      2
#define MODE_UART_ANGLE  3
// =====================================================
// CPG oscillator
// =====================================================
struct HopfOscillator {
  float r;
  float theta;
  float alpha;
  float mu;
};
// =====================================================
// Servo / Control parameters
// =====================================================
extern float servoDefaultAngles[bodyNum];
extern float angleDeg[bodyNum];
extern float Ajoint;
extern float frequency;
extern float lambda;
extern float L;
extern float ampScales[bodyNum];
extern float phaseLags[bodyNum - 1];
extern float jointBiasDeg[bodyNum];
extern bool  isPaused;
extern int   controlMode;
// =====================================================
// CPG state
// =====================================================
extern HopfOscillator cpg[bodyNum];
// ==========================
//  UART Pins
// ==========================
#define CAMERA_RX_PIN   D9
#define CAMERA_TX_PIN   D10

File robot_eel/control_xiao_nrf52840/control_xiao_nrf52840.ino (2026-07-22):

#include <Arduino.h>
#include <mbed.h>
#include <Wire.h>
#include "LSM6DS3.h"

#include "config.h"
#include "utils.h"
#include "cpg.h"
#include "servo.h"
#include "ServoStatusPacket.h"
#include "ControlParamsPacket.h"
#include "ServoTargetPacket.h"
#include "ServoCenterPacket.h"
#include "ImuPacket.h"

#define STARTUP_LOG 1

#if defined(ARDUINO_ARCH_MBED)
UART CameraSerial(
  digitalPinToPinName(CAMERA_TX_PIN),
  digitalPinToPinName(CAMERA_RX_PIN),
  NC,
  NC
);
#else
#define CameraSerial Serial
#endif

ServoStatusPacket g_status;
rtos::Mutex statusMutex;
volatile uint32_t g_servoStatusSeq = 0;

float servoDefaultAngles[bodyNum] = {120, 120, 120, 120, 120, 120};
float angleDeg[bodyNum];

float Ajoint       = 20.0f;
float frequency    = 1.0f;
float lambda       = 1.6275f;
float L            = 1.0f;
float ampScales[bodyNum] = {
  1.1f,
  0.95f,
  0.9f,
  1.071703f,
  1.161346f,
  1.273484f
};
float phaseLags[bodyNum - 1] = {
  0.614385f,
  0.622822f,
  0.615807f,
  0.615359f,
  0.608868f
};
float jointBiasDeg[bodyNum] = {0, 0, 0, 0, 0, 0};

bool isPaused = false;
int controlMode = MODE_OFFSET;

HopfOscillator cpg[bodyNum];

static ControlParamsRxState camCtrlRx;
static ServoTargetRxState camTargetRx;
static ServoCenterRxState camCenterRx;

volatile bool g_haveAngleCmd = false;
float g_uartTargetDeg[bodyNum] = {0};
volatile uint32_t g_lastAngleSeq = 0;
rtos::Mutex angleMutex;
rtos::Mutex cameraTxMutex;

static rtos::Thread servoThread(osPriorityAboveNormal, 4096, nullptr, "servoTask");
static rtos::Thread cameraTxThread(osPriorityNormal, 4096, nullptr, "cameraTxTask");
static rtos::Thread cameraRxThread(osPriorityAboveNormal, 4096, nullptr, "cameraRxTask");
static rtos::Thread servoStatusThread(osPriorityNormal, 4096, nullptr, "servoStatusTxTask");
static rtos::Thread imuThread(osPriorityNormal, 4096, nullptr, "imuTask");

static LSM6DS3 imu(I2C_MODE, 0x6A);
static bool imuReady = false;

void loadServoCenters()
{
#if STARTUP_LOG
  Serial.println("[CENTER] nRF52840 version uses built-in defaults.");
#endif
}

void saveServoCenters()
{
}

void applyServoCenters(const ServoCenterPacket &pkt)
{
  if (pkt.count != bodyNum) {
    return;
  }

  for (int i = 0; i < bodyNum; i++) {
    servoDefaultAngles[i] = constrain(pkt.centerDeg[i], 0.0f, 240.0f);
  }

  if (pkt.save) {
    saveServoCenters();
  }
}

void sendCameraControlParams()
{
  cameraTxMutex.lock();
  sendControlParamsUART(
    CameraSerial,
    Ajoint,
    frequency,
    lambda,
    L,
    ampScales,
    phaseLags,
    jointBiasDeg,
    isPaused,
    (uint8_t)controlMode,
    servoDefaultAngles
  );
  cameraTxMutex.unlock();
}

void cameraTxTask()
{
  while (true) {
    sendCameraControlParams();
    rtos::ThisThread::sleep_for(std::chrono::milliseconds(100));
  }
}

void handleControlPacket(const ControlParamsPacket &pkt)
{
  int previousMode = controlMode;

  Ajoint = pkt.Ajoint;
  frequency = pkt.frequency;
  lambda = pkt.lambda;
  L = pkt.L;

  for (int i = 0; i < bodyNum; i++) {
    ampScales[i] = pkt.ampScales[i];
    jointBiasDeg[i] = pkt.jointBiasDeg[i];
  }

  for (int i = 0; i < bodyNum - 1; i++) {
    phaseLags[i] = pkt.phaseLags[i];
  }

  isPaused = pkt.isPaused;
  controlMode = pkt.controlMode;

  if (controlMode != MODE_UART_ANGLE) {
    g_haveAngleCmd = false;
  }

  if (previousMode != MODE_CPG && controlMode == MODE_CPG) {
    initCPG();
  }
}

void serviceCameraRx()
{
  while (CameraSerial.available()) {
    uint8_t b = CameraSerial.read();

    if (camTargetRx.receiving) {
      if (feedServoTargetRx(camTargetRx, b)) {
        ServoTargetPacket &pkt = camTargetRx.pkt;

        if (pkt.count == bodyNum && pkt.seq != g_lastAngleSeq) {
          angleMutex.lock();
          for (int i = 0; i < bodyNum; i++) {
            g_uartTargetDeg[i] = pkt.targetDeg[i];
          }
          angleMutex.unlock();

          g_lastAngleSeq = pkt.seq;
          g_haveAngleCmd = true;
        }
      }
      continue;
    }

    if (camCenterRx.receiving) {
      if (feedServoCenterRx(camCenterRx, b)) {
        applyServoCenters(camCenterRx.pkt);
      }
      continue;
    }

    if (camCtrlRx.receiving) {
      if (feedControlParamsRx(camCtrlRx, b)) {
        handleControlPacket(camCtrlRx.pkt);
      }
      continue;
    }

    if (b == CONTROL_PARAMS_PACKET_HEADER) {
      feedControlParamsRx(camCtrlRx, b);
      continue;
    }

    if (b == SERVO_TARGET_PACKET_HEADER) {
      feedServoTargetRx(camTargetRx, b);
      continue;
    }

    if (b == SERVO_CENTER_PACKET_HEADER) {
      feedServoCenterRx(camCenterRx, b);
      continue;
    }
  }
}

void cameraRxTask()
{
  while (true) {
    serviceCameraRx();
    rtos::ThisThread::sleep_for(std::chrono::milliseconds(1));
  }
}

void servoStatusTxTask()
{
  while (true) {
    cameraTxMutex.lock();
    sendServoStatusUART(CameraSerial);
    cameraTxMutex.unlock();
    rtos::ThisThread::sleep_for(std::chrono::milliseconds(80));
  }
}

void imuTask()
{
  static uint32_t seq = 0;

  while (true) {
    if (imuReady) {
      cameraTxMutex.lock();
      sendImuPacketUART(
        CameraSerial,
        seq++,
        millis(),
        imu.readFloatAccelX(),
        imu.readFloatAccelY(),
        imu.readFloatAccelZ(),
        imu.readFloatGyroX(),
        imu.readFloatGyroY(),
        imu.readFloatGyroZ(),
        imu.readTempC()
      );
      cameraTxMutex.unlock();
    }

    rtos::ThisThread::sleep_for(std::chrono::milliseconds(20));
  }
}

void setup()
{
  Serial.begin(115200);
  uint32_t serialWaitStart = millis();
  while (!Serial && millis() - serialWaitStart < 1000) {
    delay(10);
  }
  delay(300);

  Serial1.begin(115200);
  CameraSerial.begin(115200);

#if STARTUP_LOG
  Serial.println("XIAO nRF52840 Control Board Ready");
#endif
  loadServoCenters();

#if defined(PIN_LSM6DS3TR_C_POWER)
  pinMode(PIN_LSM6DS3TR_C_POWER, OUTPUT);
  digitalWrite(PIN_LSM6DS3TR_C_POWER, HIGH);
  delay(10);
#endif
  Wire.begin();

  if (imu.begin() == 0) {
    imuReady = true;
#if STARTUP_LOG
    Serial.println("[IMU] LSM6DS3 ready");
#endif
  } else {
    imuReady = false;
#if STARTUP_LOG
    Serial.println("[IMU] LSM6DS3 init failed");
#endif
  }
  initCPG();

  servoThread.start(servoTask);
  cameraTxThread.start(cameraTxTask);
  cameraRxThread.start(cameraRxTask);
  servoStatusThread.start(servoStatusTxTask);
  imuThread.start(imuTask);
}

void loop()
{
  delay(1000);
}

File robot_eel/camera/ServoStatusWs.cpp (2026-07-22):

#include "ServoStatusWs.h"

#include <ArduinoJson.h>
#include <cstdlib>
#include <esp_heap_caps.h>

#include "config.h"

namespace {

WebSocketsServer *g_ws = nullptr;

unsigned long lastBroadcast = 0;
constexpr unsigned long BROADCAST_INTERVAL_MS = 25;

struct ServoStatusPacketLogEntry {
    uint32_t seq;
    uint32_t millisValue;
    uint8_t count;
    float targetDeg[SERVO_STATUS_MAX];
    float actualDeg[SERVO_STATUS_MAX];
    float errorDeg[SERVO_STATUS_MAX];
};

constexpr size_t LOG_CAPACITY = 1200;
ServoStatusPacketLogEntry *logBuffer = nullptr;
size_t logHead = 0;
size_t logSize = 0;

struct ImuPacketLogEntry {
    uint32_t seq;
    uint32_t millisValue;
    uint32_t tMs;
    float accel[3];
    float gyro[3];
    float tempC;
};

constexpr size_t IMU_LOG_CAPACITY = 3000;
ImuPacketLogEntry *imuLogBuffer = nullptr;
size_t imuLogHead = 0;
size_t imuLogSize = 0;

template <typename T>
T *allocateLogBuffer(size_t count)
{
    void *ptr = heap_caps_malloc(sizeof(T) * count, MALLOC_CAP_SPIRAM | MALLOC_CAP_8BIT);
    if (!ptr) {
        ptr = heap_caps_malloc(sizeof(T) * count, MALLOC_CAP_8BIT);
    }
    return static_cast<T *>(ptr);
}

void appendLog(
    uint8_t count,
    uint32_t seq,
    const float *target,
    const float *actual,
    const float *error)
{
    if (!logBuffer) return;

    ServoStatusPacketLogEntry &entry = logBuffer[logHead];
    entry.seq = seq;
    entry.millisValue = millis();
    entry.count = count < SERVO_STATUS_MAX ? count : SERVO_STATUS_MAX;

    for (uint8_t i = 0; i < entry.count; i++) {
        entry.targetDeg[i] = target[i];
        entry.actualDeg[i] = actual[i];
        entry.errorDeg[i] = error[i];
    }

    logHead = (logHead + 1) % LOG_CAPACITY;
    if (logSize < LOG_CAPACITY) {
        logSize++;
    }
}

void appendImuLog(const ImuPacket &imu)
{
    if (!imuLogBuffer) return;

    ImuPacketLogEntry &entry = imuLogBuffer[imuLogHead];
    entry.seq = imu.seq;
    entry.millisValue = millis();
    entry.tMs = imu.t_ms;
    entry.tempC = imu.tempC;

    for (uint8_t i = 0; i < 3; i++) {
        entry.accel[i] = imu.accel[i];
        entry.gyro[i] = imu.gyro[i];
    }

    imuLogHead = (imuLogHead + 1) % IMU_LOG_CAPACITY;
    if (imuLogSize < IMU_LOG_CAPACITY) {
        imuLogSize++;
    }
}

} // namespace

void ServoStatusWs::begin(WebSocketsServer &ws)
{
    g_ws = &ws;

    if (!logBuffer) {
        logBuffer = allocateLogBuffer<ServoStatusPacketLogEntry>(LOG_CAPACITY);
        if (!logBuffer) {
            Serial.println("[SERVO CSV] log buffer allocation failed");
        }
    }

    if (!imuLogBuffer) {
        imuLogBuffer = allocateLogBuffer<ImuPacketLogEntry>(IMU_LOG_CAPACITY);
        if (!imuLogBuffer) {
            Serial.println("[IMU CSV] log buffer allocation failed");
        }
    }

    CtrlUartBridge::onServoStatusPacket =
        [](const ServoStatusPacket &s)
        {
            ServoStatusWs::broadcast(
                s.count,
                s.seq,
                s.targetDeg,
                s.actualDeg,
                s.errorDeg
            );
        };

    CtrlUartBridge::onImuPacket =
        [](const ImuPacket &imu)
        {
            ServoStatusWs::broadcastImu(imu);
        };
}

void ServoStatusWs::broadcast(
    uint8_t count,
    uint32_t seq,
    const float *target,
    const float *actual,
    const float *error)
{
    appendLog(count, seq, target, actual, error);

    if (!g_ws) return;

    unsigned long now = millis();
    if (now - lastBroadcast < BROADCAST_INTERVAL_MS) return;
    lastBroadcast = now;

    StaticJsonDocument<512> doc;
    doc["type"] = "servo_status";
    doc["seq"] = seq;

    JsonArray t = doc.createNestedArray("target");
    JsonArray a = doc.createNestedArray("actual");
    JsonArray e = doc.createNestedArray("error");

    const uint8_t safeCount = count < SERVO_STATUS_MAX ? count : SERVO_STATUS_MAX;
    for (uint8_t i = 0; i < safeCount; i++) {
        t.add(target[i]);
        a.add(actual[i]);
        e.add(error[i]);
    }

    String out;
    serializeJson(doc, out);
    g_ws->broadcastTXT(out);
}

void ServoStatusWs::broadcastImu(const ImuPacket &imu)
{
    appendImuLog(imu);

    if (!g_ws) return;

    StaticJsonDocument<384> doc;
    doc["type"] = "imu_status";
    doc["seq"] = imu.seq;
    doc["t_ms"] = imu.t_ms;
    doc["tempC"] = imu.tempC;

    JsonArray accel = doc.createNestedArray("accel");
    JsonArray gyro = doc.createNestedArray("gyro");

    for (uint8_t i = 0; i < 3; i++) {
        accel.add(imu.accel[i]);
        gyro.add(imu.gyro[i]);
    }

    String out;
    serializeJson(doc, out);
    g_ws->broadcastTXT(out);
}

void ServoStatusWs::clearLog()
{
    logHead = 0;
    logSize = 0;
}

void ServoStatusWs::clearImuLog()
{
    imuLogHead = 0;
    imuLogSize = 0;
}

size_t ServoStatusWs::logCount()
{
    if (!logBuffer) return 0;
    return logSize;
}

size_t ServoStatusWs::imuLogCount()
{
    if (!imuLogBuffer) return 0;
    return imuLogSize;
}

void ServoStatusWs::sendCsv(WebServer &server)
{
    if (!logBuffer) {
        server.send(503, "text/plain", "servo log buffer unavailable");
        return;
    }

    const size_t countSnapshot = logSize;
    const size_t headSnapshot = logHead;
    const size_t start = (headSnapshot + LOG_CAPACITY - countSnapshot) % LOG_CAPACITY;

    server.setContentLength(CONTENT_LENGTH_UNKNOWN);
    server.send(200, "text/csv", "");
    server.sendContent("seq,millis,channel,target_deg,actual_deg,error_deg\n");

    char line[128];
    for (size_t i = 0; i < countSnapshot; i++) {
        const ServoStatusPacketLogEntry &entry = logBuffer[(start + i) % LOG_CAPACITY];
        for (uint8_t ch = 0; ch < entry.count; ch++) {
            snprintf(
                line,
                sizeof(line),
                "%lu,%lu,CH%u,%.3f,%.3f,%.3f\n",
                static_cast<unsigned long>(entry.seq),
                static_cast<unsigned long>(entry.millisValue),
                static_cast<unsigned int>(ch + 1),
                entry.targetDeg[ch],
                entry.actualDeg[ch],
                entry.errorDeg[ch]
            );
            server.sendContent(line);
        }
    }

    server.sendContent("");
}
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

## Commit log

2026-06-09 Initial robot eel simulation package
    [base_link.STL, clean_v_20260606_222425_composite_metrics.csv, clean_v_20260606_224117_composite_metrics.csv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]
2026-06-09 Restore mesh fluid and set head mass
    [water_settings.xml]
2026-06-10 Add full real and MuJoCo gait pipeline buttons to GUI
2026-06-10 Smooth rectangle course steering at maximum turn
2026-06-11 Port Python Hopf CPG coupling to control firmware
2026-06-11 Use synchronous CPG update in servo task
2026-06-11 Probe 8s then measure straight for 13s
2026-06-11 Filter invalid short corner real tracks
2026-06-11 Use robust multi-candidate real video tracking flow
2026-06-22 Set default joint amplitude to 20 degrees
2026-06-22 Fix mutex creation after Ajoint update
    [control.ino]
2026-06-22 Set backend default joint amplitude to 20 degrees
2026-06-26 Update simulation outputs and ignore videos
    [command_error_summary.csv, ew08_a20_targetv17_ppo_free_swim_freq_phase_run01_eval_best_policy_trajectory.csv, ew08_a20_targetv17_ppo_free_swim_freq_phase_run01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]
2026-07-07 Ignore generated data outputs
    [backward_negfreq_w100_ew08_a20_targetv11_ppo_free_swim_freq_phase_run01_eval_best_policy_trajectory.csv, backward_negfreq_w100_ew08_a20_targetv11_ppo_free_swim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]
